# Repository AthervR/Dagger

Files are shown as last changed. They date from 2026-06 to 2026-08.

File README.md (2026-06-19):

# Dagger — GPS-Guided Model Rocket Flight Computer

**Dagger** is a custom flight computer built around the **Teensy 4.1** microcontroller for a GPS-guided high-powered model rocket. The goal is active trajectory correction using real-time GPS positioning and inertial navigation, with onboard data logging for post-flight analysis.

## Hardware

| Component | Interface | Role |
|---|---|---|
| Teensy 4.1 | — | Main flight computer (600 MHz ARM Cortex-M7) |
| ICM-20948 9-DOF IMU | SPI0, CS pin 10 | Accelerometer (±16g), gyroscope (±2000 dps), magnetometer |
| BMP390 Barometer | SPI0, CS pin 9 | Pressure-based altitude, ±0.03 hPa resolution |
| SSD1306 0.91" OLED | I2C0 (pins 18/19) | Real-time status display on the ground |
| u-blox NEO-M9N GPS | UART1 (pins 0/1) | High-sensitivity L1 GNSS, 5 Hz position updates |
| MicroSD (SDIO) | Built-in Teensy 4.1 slot | Flight log — IMU, baro, GPS at full data rates |

## GPS Guided Mode

The primary mission of Dagger is **GPS-in-the-loop guidance**. After motor burnout, the flight computer compares the rocket's real-time GPS position against a pre-loaded target trajectory. Corrections are computed and fed to control surfaces (fins or thrust vectoring, TBD) to minimize lateral deviation from the intended flight path.

Key guidance elements:
- **NEO-M9N** provides 5 Hz position/velocity fixes with 1 PPS timing pulse for EKF time synchronization
- **ICM-20948** runs at ~225 Hz to bridge GPS update gaps with dead-reckoning via the onboard EKF
- **BMP390** provides barometric altitude at 25 Hz for vertical channel augmentation
- Magnetometer cross-checks heading independent of GPS course-over-ground

## Firmware Architecture

The MK2 firmware (`src/Dagger_1_MK2_Code.cpp`) is a bring-up / sensor validation sketch. All sensor inits are non-fatal — the flight computer boots and logs status for any subset of connected hardware, making incremental protoboard assembly straightforward.

```
Loop at ~1 kHz:
  ├── IMU poll @ 200 Hz (getAGMT — accel + gyro + mag in one SPI burst)
  ├── Baro poll @ 25 Hz (forced-mode, ~20 ms conversion)
  ├── GPS @ 5 Hz via pvt_callback (UBX NAV-PVT packet)
  ├── Serial monitor @ 2 Hz (all sensor data or OFFLINE notices)
  └── OLED update @ 2 Hz (4-row 128×32 status display)
```

OLED layout (128×32, 4 rows):
```
I:OK B:OK G:OK S:OK      ← component live/offline status
 0.0  0.0  1.0g           ← IMU acceleration in g
 142m 21.3C               ← baro altitude and temperature
GPS 3D 8sv                ← GPS fix type and satellite count
```

## Build

Requires [PlatformIO](https://platformio.org/) with the Teensy platform.

```ini
platform = teensy
board = teensy41
framework = arduino
```

**Dependencies** (installed automatically by PlatformIO):
- `sparkfun/SparkFun 9DoF IMU Breakout - ICM 20948`
- `adafruit/Adafruit BMP3XX Library`
- `adafruit/Adafruit SSD1306` + GFX + BusIO
- `sparkfun/SparkFun u-blox GNSS Arduino Library`

**Upload:** Use the PlatformIO **Upload** button (→ in the VS Code status bar), not the VS Code Run button. Teensy uses the HalfKay USB bootloader — press the physical button on the board when prompted.

## Status

Currently in hardware bring-up. Wiring components to protoboard one by one. Guidance algorithm and EKF implementation are next after full sensor validation.

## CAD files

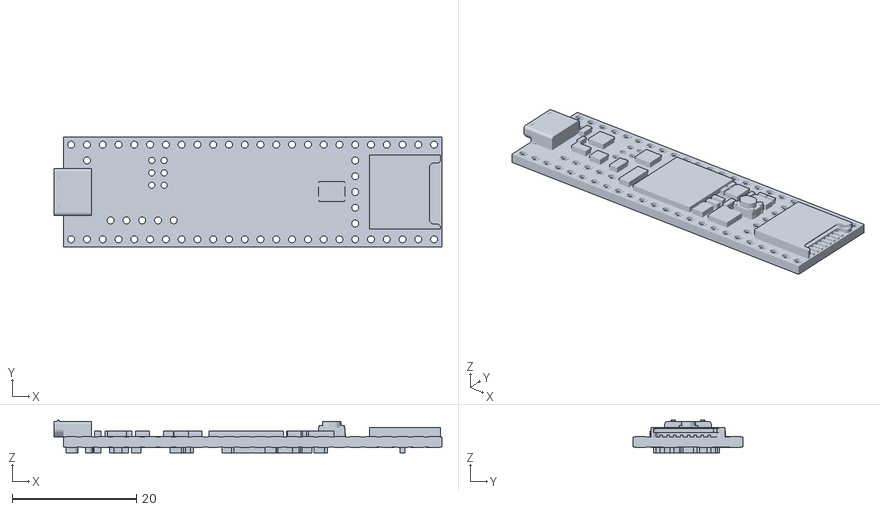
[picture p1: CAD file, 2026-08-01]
CAD Files/Teensy 4.1.stl
62.5 x 17.8 x 5.27

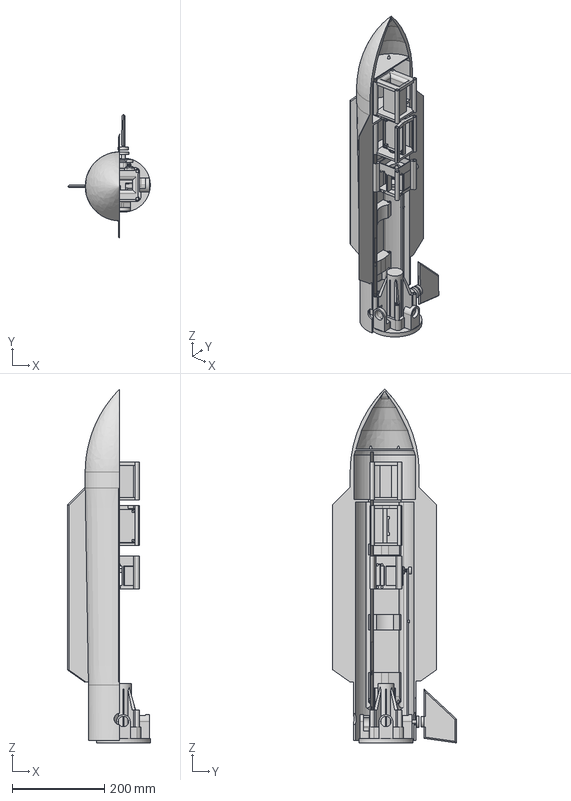
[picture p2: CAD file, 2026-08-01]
CAD Files/AirframeV1.step
179.4 x 268.7 x 768.6 mm
Servo Horn
ACS Pin
ACS Cam
Fin
FC Case
Bottom
GPS Case
Screw
Servo/Cam Linkage
Carbon Support Rod
Casing

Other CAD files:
CAD Files/AirframeV1.obj
CAD Files/AirframeV1.stl

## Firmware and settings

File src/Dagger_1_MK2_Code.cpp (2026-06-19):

/**
 * Flight Computer Hardware Bring-Up Sketch
 * Teensy 4.1
 *
 * Devices:
 *   ICM-20948  9-DOF IMU     — SPI0,  CS pin 10, INT pin 8
 *   BMP390     Barometer     — SPI0,  CS pin 9  (shares bus with IMU), INT pin 7 (optional)
 *   SSD1306    0.91" OLED    — I2C0,  address 0x3C
 *   NEO-M9N    GPS           — UART1, pins 0(RX) / 1(TX), PPS pin 2
 *   microSD    Flight log    — SDIO   (Teensy 4.1 built-in slot, no GPIO cost)
 *
 * Required libraries (Arduino Library Manager):
 *   "SparkFun 9DoF IMU Breakout - ICM 20948"   by SparkFun Electronics
 *   "Adafruit BMP3XX Library"                   by Adafruit  (+BusIO dependency)
 *   "Adafruit SSD1306"                          by Adafruit  (+GFX dependency)
 *   Teensy SD (bundled with Teensyduino — do NOT install a separate SD library)
 *
 * Note on "Multiple libraries found for SD.h":
 *   This warning is benign. Arduino IDE correctly uses the Teensy-bundled SD
 *   library (packages/teensy/.../SD) which is the only one that supports
 *   BUILTIN_SDCARD and the Teensy 4.1 SDIO interface. The others are ignored.
 */

#include <Arduino.h>
#include <SPI.h>
#include <Wire.h>
#include "ICM_20948.h"          // SparkFun 9DoF IMU Breakout - ICM 20948
#include <Adafruit_BMP3XX.h>    // Adafruit BMP3XX
#include <Adafruit_SSD1306.h>   // Adafruit SSD1306
#include <SD.h>                 // Teensy-bundled SD (SDIO)
#include <SparkFun_u-blox_GNSS_Arduino_Library.h>  // SparkFun u-blox GNSS v2

// =============================================================================
// Pin assignments
// =============================================================================
constexpr uint8_t PIN_CS_IMU  = 10;   // SPI chip-select: ICM-20948
constexpr uint8_t PIN_CS_BARO =  9;   // SPI chip-select: BMP390
constexpr uint8_t PIN_INT_IMU =  8;   // Data-ready interrupt from ICM-20948
constexpr uint8_t PIN_INT_BARO=  7;   // Data-ready interrupt from BMP390 (optional)
constexpr uint8_t PIN_GPS_PPS =  2;   // GPS 1 PPS — latched with micros() for EKF time sync

// =============================================================================
// Peripheral objects
// =============================================================================
ICM_20948_SPI    imu;
Adafruit_BMP3XX  baro;
Adafruit_SSD1306 oled(128, 32, &Wire);   // 0.91" SSD1306, I2C0
SFE_UBLOX_GNSS   gnss;                   // NEO-M9N over UART1

// Component status flags — set during setup(), read in loop() and OLED update
bool imu_ok  = false;
bool baro_ok = false;
bool oled_ok = false;
bool sd_ok   = false;
bool gps_ok  = false;

// =============================================================================
// IMU data-ready interrupt
// =============================================================================
volatile bool imu_data_ready = false;
void imu_isr() { imu_data_ready = true; }

// =============================================================================
// GPS PPS interrupt — latches MCU microsecond counter on each rising edge.
// One pulse per second (after fix). EKF uses this to correlate MCU time with
// GPS time-of-week from NAV-PVT iTOW field.
// =============================================================================
volatile uint32_t pps_timestamp_us = 0;
void pps_isr() { pps_timestamp_us = micros(); }

// =============================================================================
// GPS state — populated by pvt_callback()
// =============================================================================
struct GpsState {
  double  lat    = 0.0;    // degrees
  double  lon    = 0.0;    // degrees
  float   alt_m  = 0.0f;   // metres MSL
  float   spd_ms = 0.0f;   // ground speed m/s
  uint8_t fix    = 0;      // 0=no fix, 2=2D, 3=3D
  uint8_t sats   = 0;      // satellites used
  bool    fresh  = false;  // cleared by consumer after reading
} gps;

// =============================================================================
// Forward declarations
// =============================================================================
void pvt_callback(UBX_NAV_PVT_data_t d);
void pps_isr();

// =============================================================================
// GPS PVT callback — fired by gnss.checkCallbacks() on each new NAV-PVT packet
// =============================================================================
void pvt_callback(UBX_NAV_PVT_data_t d) {
  gps.fix    = d.fixType;
  gps.sats   = d.numSV;
  gps.lat    = d.lat    * 1e-7;
  gps.lon    = d.lon    * 1e-7;
  gps.alt_m  = d.hMSL  * 0.001f;
  gps.spd_ms = d.gSpeed * 0.001f;
  gps.fresh  = true;
}

// =============================================================================
// Setup
// =============================================================================
void setup() {
  pinMode(LED_BUILTIN, OUTPUT);
  digitalWrite(LED_BUILTIN, HIGH);  // solid ON during boot

  Serial.begin(115200);
  // Wait up to 3 s for USB serial monitor.
  // REMOVE for flight firmware — stalls boot if no PC is connected.
  while (!Serial && millis() < 3000);
  Serial.println("\n[BOOT] Flight computer bring-up starting");

  // SPI0 — Sensor bus
  SPI.begin();
  pinMode(PIN_CS_IMU,  OUTPUT); digitalWrite(PIN_CS_IMU,  HIGH);
  pinMode(PIN_CS_BARO, OUTPUT); digitalWrite(PIN_CS_BARO, HIGH);

  imu.begin(PIN_CS_IMU, SPI, 4000000);   // 4 MHz — conservative for bring-up (max is 7 MHz)
  imu_ok = (imu.status == ICM_20948_Stat_Ok);
  if (!imu_ok) {
    Serial.println("[IMU ] FAIL — verify MOSI(11)/MISO(12)/SCK(13)/CS(10) and 3.3V");
  } else {
    imu.sleep(true);
    imu.lowPower(false);
    imu.setSampleMode(
      (ICM_20948_Internal_Acc | ICM_20948_Internal_Gyr),
      ICM_20948_Sample_Mode_Continuous
    );

    // Sample rate = 1125 Hz / (1 + divisor); divisor 4 → ~225 Hz
    ICM_20948_smplrt_t rate;
    rate.a = 4; rate.g = 4;
    imu.setSampleRate((ICM_20948_Internal_Acc | ICM_20948_Internal_Gyr), rate);

    ICM_20948_fss_t fss;
    fss.a = gpm16;     // ±16 g — handles launch spike
    fss.g = dps2000;   // ±2000 dps — handles spin recovery
    imu.setFullScale((ICM_20948_Internal_Acc | ICM_20948_Internal_Gyr), fss);

    // Highest DLPF bandwidth — minimise phase lag into the EKF
    ICM_20948_dlpcfg_t dlp;
    dlp.a = acc_d473bw_n499bw;
    dlp.g = gyr_d361bw4_n376bw5;
    imu.setDLPFcfg((ICM_20948_Internal_Acc | ICM_20948_Internal_Gyr), dlp);
    imu.enableDLPF(ICM_20948_Internal_Acc, true);
    imu.enableDLPF(ICM_20948_Internal_Gyr, true);

    // INT1: active-high, push-pull, pulse, fires on data-ready
    imu.cfgIntActiveLow(false);
    imu.cfgIntOpenDrain(false);
    imu.cfgIntLatch(false);
    imu.intEnableRawDataReady(true);
    imu.sleep(false);

    // AK09916 mag runs via ICM's internal I2C master; max 100 Hz and NOT
    // synchronous with accel/gyro. Timestamp mag separately in the EKF.
    imu.startupMagnetometer();
    Serial.println("[IMU ] OK — ±16g, ±2000dps, AK09916 mag started");
  }

  baro_ok = baro.begin_SPI(PIN_CS_BARO);
  if (!baro_ok) {
    Serial.println("[BARO] FAIL — verify CS(9); shares SPI0 with IMU");
  } else {
    baro.setTemperatureOversampling(BMP3_OVERSAMPLING_2X);
    baro.setPressureOversampling(BMP3_OVERSAMPLING_8X);
    baro.setIIRFilterCoeff(BMP3_IIR_FILTER_COEFF_3);
    // ODR 25 Hz (40 ms period). BMP390 datasheet §3.9.2: t_meas with 8× press +
    // 2× temp = 234 + 8×2020 + 2×2020 = ~20.4 ms, which exceeds the 20 ms period
    // needed for 50 Hz. 25 Hz gives a 40 ms window — measurement completes with
    // ~20 ms to spare. NOTE: performReading() uses forced-mode so setOutputDataRate
    // is advisory only; the actual poll interval is controlled in loop() below.
    baro.setOutputDataRate(BMP3_ODR_25_HZ);
    Serial.println("[BARO] OK — 25 Hz, pressure ×8, IIR coeff 3");
  }

  // I2C0 — OLED
  Wire.begin();
  Wire.setClock(400000);
  oled_ok = oled.begin(SSD1306_SWITCHCAPVCC, 0x3C);
  if (!oled_ok) {
    // Try 0x3D if this fires — some modules use the alternate address
    Serial.println("[OLED] Init failed — non-fatal, continuing");
  } else {
    oled.clearDisplay();
    oled.setTextSize(1);
    oled.setTextColor(SSD1306_WHITE);
    oled.setCursor(0, 0); oled.print("Flight computer");
    oled.setCursor(0, 9); oled.print("Initializing...");
    oled.display();
    Serial.println("[OLED] OK");
  }

  // SDIO — built-in microSD
  sd_ok = SD.begin(BUILTIN_SDCARD);
  if (!sd_ok) {
    Serial.println("[SD  ] FAIL — check card seated; logging disabled");
  } else {
    Serial.println("[SD  ] OK");
  }

  // UART1 — GPS (NEO-M9N, SparkFun u-blox GNSS v2)
  // The module emits a startup banner before accepting UBX traffic — 500 ms
  // settle prevents the handshake racing against it.
  // Try 115200 first (previously saved config), fall back to factory default 38400.
  // Do NOT attempt a baud-rate switch here; stay on whichever rate responds.
  Serial1.begin(115200);
  delay(500);
  gps_ok = gnss.begin(Serial1);
  if (!gps_ok) {
    Serial.println("[GPS ] 115200 no ACK — trying factory default 38400...");
    Serial1.end();
    Serial1.begin(38400);
    delay(500);
    gps_ok = gnss.begin(Serial1);
  }
  if (gps_ok) {
    gnss.setUART1Output(COM_TYPE_UBX);   // switch GPS output to UBX binary only
    gnss.setNavigationFrequency(5);      // 5 Hz — reliable on both baud rates
    gnss.setAutoPVTcallback(pvt_callback);
    gnss.saveConfiguration();
    Serial.println("[GPS ] OK — 5 Hz NAV-PVT, callback armed");
  } else {
    Serial.println("[GPS ] FAIL — check TX(1)/RX(0) wiring");
  }

  // Interrupts — attach last, after all peripheral init complete
  //pinMode(PIN_INT_IMU,  INPUT);
  //attachInterrupt(digitalPinToInterrupt(PIN_INT_IMU),  imu_isr, RISING);

  pinMode(PIN_INT_BARO, INPUT);   // INT_BARO: not yet used (polling mode); reserve pin

  // GPS PPS: rising edge latched by pps_isr() for EKF time sync.
  // NEO-M9N outputs PPS once per second after achieving a time fix.
  pinMode(PIN_GPS_PPS, INPUT);
  attachInterrupt(digitalPinToInterrupt(PIN_GPS_PPS), pps_isr, RISING);

  Serial.println("[BOOT] All subsystems ready\n");
}

// =============================================================================
// Loop
// =============================================================================
void loop() {
  static uint32_t last_baro_ms     = 0;
  static uint32_t last_print_ms    = 0;
  static uint32_t last_oled_ms     = 0;
  static uint32_t last_gps_seek_ms = 0;
  static float    baro_alt_m       = 0.0f;
  static float    baro_temp_c      = 0.0f;
  static bool     gps_had_fix      = false;

  // IMU: service data-ready at ~225 Hz
  // getAGMT() bursts accel + gyro + mag + temp in one SPI transaction.
  // accX/Y/Z → mg;  gyrX/Y/Z → dps
  static uint32_t last_imu_ms = 0;
  if (imu_ok && millis() - last_imu_ms >= 5) {   // 200 Hz poll — matches your ~225 Hz ODR
    last_imu_ms = millis();
    imu.getAGMT();
  }

  // Baro: poll at 25 Hz (40 ms). performReading() blocks ~20 ms in forced-mode;
  // keeping the window at 40 ms prevents it from starving the IMU handler.
  // For flight firmware replace with INT_BARO interrupt + non-blocking normal mode.
  if (baro_ok && millis() - last_baro_ms >= 40) {
    last_baro_ms = millis();
    if (baro.performReading()) {
      baro_alt_m  = baro.readAltitude(1013.25f);
      baro_temp_c = (float)baro.temperature;
    }
  }

  // GPS: process incoming bytes and fire pvt_callback when a full packet arrives
  if (gps_ok) {
    gnss.checkUblox();
    gnss.checkCallbacks();
  }

  // GPS seek monitor — every 30 s, log status to Serial until first 3-D fix
  if (gps_ok && !gps_had_fix) {
    if (gps.fix >= 3) {
      gps_had_fix = true;
      Serial.printf("[GPS ] First 3D fix! lat:%.6f lon:%.6f alt:%.1fm sats:%d (%.0fs elapsed)\n",
                    gps.lat, gps.lon, gps.alt_m, gps.sats, millis() / 1000.0f);
    } else if (millis() - last_gps_seek_ms >= 30000) {
      last_gps_seek_ms = millis();
      Serial.printf("[GPS ] Seeking... %ds elapsed  sats visible:%d  fix type:%d\n",
                    (int)(millis() / 1000), gps.sats, gps.fix);
    }
  }

  // Serial monitor at 2 Hz
  if (millis() - last_print_ms >= 500) {
    last_print_ms = millis();

    if (imu_ok) {
      Serial.printf("IMU  ax:%8.1f ay:%8.1f az:%8.1f mg   gx:%7.2f gy:%7.2f gz:%7.2f dps\n",
                    imu.accX(), imu.accY(), imu.accZ(),
                    imu.gyrX(), imu.gyrY(), imu.gyrZ());
    } else {
      Serial.println("IMU  OFFLINE");
    }

    if (baro_ok) {
      Serial.printf("BARO alt:%7.1f m   temp:%.1f C\n", baro_alt_m, baro_temp_c);
    } else {
      Serial.println("BARO OFFLINE");
    }

    if (!gps_ok) {
      Serial.println("GPS  OFFLINE");
    } else if (gps.fresh) {
      Serial.printf("GPS  fix:%d sats:%2d  lat:%11.6f  lon:%11.6f  alt:%7.1fm  spd:%.2fm/s\n",
                    gps.fix, gps.sats, gps.lat, gps.lon, gps.alt_m, gps.spd_ms);
      gps.fresh = false;
    } else {
      Serial.println("GPS  awaiting first fix...");
    }

    if (imu_ok) {
      Serial.printf("MAG  mx:%7.2f my:%7.2f mz:%7.2f uT\n",
                    imu.magX(), imu.magY(), imu.magZ());
    }

    // PPS: age since last pulse (0 before first fix)
    uint32_t pps_us = pps_timestamp_us;   // snapshot volatile
    if (pps_us > 0)
      Serial.printf("PPS  last pulse %lu ms ago\n", (millis() * 1000UL - pps_us) / 1000UL);
    else
      Serial.println("PPS  awaiting first pulse...");

    Serial.println();
  }

  // OLED at 2 Hz — 128×32, textSize 1 = 6×8px per char, 4 rows at y=0/8/16/24
  //
  // Row 0: I:OK B:-- G:-- S:--   (component status)
  // Row 1: IMU accel in g        (or "IMU: OFFLINE")
  // Row 2: baro alt + temp       (or "BARO: OFFLINE")
  // Row 3: GPS status            (or "GPS: OFFLINE")
  if (oled_ok && millis() - last_oled_ms >= 500) {
    last_oled_ms = millis();
    char line[22];

    oled.clearDisplay();

    // Row 0: component status
    snprintf(line, sizeof(line), "I:%s B:%s G:%s S:%s",
             imu_ok  ? "OK" : "--",
             baro_ok ? "OK" : "--",
             gps_ok  ? "OK" : "--",
             sd_ok   ? "OK" : "--");
    oled.setCursor(0, 0); oled.print(line);

    // Row 1: IMU accelerometer (converted from mg to g) or offline notice
    if (imu_ok) {
      snprintf(line, sizeof(line), "%.1f %.1f %.1fg",
               imu.accX() / 1000.0f, imu.accY() / 1000.0f, imu.accZ() / 1000.0f);
    } else {
      snprintf(line, sizeof(line), "IMU: OFFLINE");
    }
    oled.setCursor(0, 8); oled.print(line);

    // Row 2: barometer altitude and temperature or offline notice
    if (baro_ok) {
      snprintf(line, sizeof(line), "%.0fm %.1fC", baro_alt_m, baro_temp_c);
    } else {
      snprintf(line, sizeof(line), "BARO: OFFLINE");
    }
    oled.setCursor(0, 16); oled.print(line);

    // Row 3: GPS fix status, seeking info, or offline notice
    if (!gps_ok) {
      snprintf(line, sizeof(line), "GPS: OFFLINE");
    } else if (gps.fix >= 2) {
      snprintf(line, sizeof(line), "GPS %s %dsv",
               gps.fix >= 3 ? "3D" : "2D", gps.sats);
    } else {
      uint32_t elapsed_s = millis() / 1000;
      snprintf(line, sizeof(line), "SEEK %dsv %dm%02ds",
               gps.sats, elapsed_s / 60, elapsed_s % 60);
    }
    oled.setCursor(0, 24); oled.print(line);

    oled.display();
  }

  // LED stage indicator (non-blocking)
  // solid ON = 3D fix | 2 Hz = 2D fix | 1 Hz = no fix or GPS offline
  {
    static uint32_t last_led_ms = 0;
    static bool     led_state   = false;
    uint32_t interval = (gps_ok && gps.fix >= 3) ? 0 :    // solid ON — 3D fix
                        (gps_ok && gps.fix == 2) ? 250 :   // 2 Hz    — 2D fix
                                                    500;    // 1 Hz    — no fix / GPS offline
    if (interval == 0) {
      digitalWrite(LED_BUILTIN, HIGH);
    } else if (millis() - last_led_ms >= interval) {
      last_led_ms = millis();
      led_state = !led_state;
      digitalWrite(LED_BUILTIN, led_state);
    }
  }
}
